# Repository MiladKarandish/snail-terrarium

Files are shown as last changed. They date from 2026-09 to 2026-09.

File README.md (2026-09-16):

# Automated Snail Terrarium

A smart, self-regulating snail habitat: a 46 × 28 × 37 cm moss-covered terrarium
with closed-loop humidity, temperature and light control, driven by an ESP8266
running [**Climate Panel Pro**](https://github.com/MiladKarandish/esp8266-climate-pro)
firmware. No cloud, no app — the controller serves its own real-time web
dashboard over WiFi.

> **Status:** the printed mist chamber is designed, verified (57/57) and being
> ordered. Hardware is specified; wiring, firmware configuration and tuning are
> in progress.

---

## 1. What this is

Land snails are simple to keep and unforgiving about exactly one thing: **the
climate**. Too dry and they seal themselves into their shells and stop eating;
too wet and stagnant and the tank grows mould and bacteria. Doing that by hand
means misting twice a day, every day, forever.

This project closes the loop:

- An **SHT31-D** sensor reads temperature and relative humidity inside the tank.
- When humidity drops below target, an **ultrasonic mist maker** fogs the tank.
- When humidity overshoots — or on a scheduled interval — a **fan** exchanges air.
- A **neon LED strip** runs a circadian day/night cycle so the live **moss**
  carpet gets a real photoperiod and the snails get a stable dawn/dusk rhythm.
- Everything is visible and adjustable from a phone browser on the local network.

### Design goals

| Goal | How |
|---|---|
| Hold 75–90 %RH without manual misting | SHT31-D → mist maker, hysteresis control |
| Keep air fresh, prevent mould | Fan on humidity ceiling + timed air exchange |
| Real day/night for moss and snails | PWM LED strip on a sunrise/sunset curve |
| Never cook or drown the animals | Sensor-fault failsafe forces outputs off |
| Fully local, no subscriptions | ESP8266 web dashboard, WebSocket, mDNS |
| Repairable and documented | Every pin mirrored in [HARDWARE.md](HARDWARE.md) |

---

## 2. The habitat

| Property | Value |
|---|---|
| Enclosure | Glass/acrylic terrarium, **46 × 28 × 37 cm** (L × W × H) |
| Volume | ≈ **47.7 L** (0.048 m³) |
| Floor area | ≈ **1288 cm²** |
| Substrate | Coco coir / peat + sphagnum, 5–8 cm deep (snails burrow to lay eggs) |
| Planting | Live moss carpet (sheet/cushion moss), optional ferns |
| Furnishing | Cork bark hides, calcium/cuttlebone dish, shallow water dish, food dish |
| Lid | Escape-proof, ventilated — snails climb everything and lift light lids |

### Climate targets

Defaults below assume a temperate species (e.g. *Cornu aspersum*, the common
garden snail). **Confirm against your species** before committing setpoints —
giant African land snails want it warmer (24–27 °C).

| Parameter | Target | Acceptable | Notes |
|---|---|---|---|
| Temperature | **20–22 °C** | 18–24 °C | Above ~26 °C is stressful; above 30 °C dangerous |
| Humidity | **80 %RH** | 75–90 %RH | Below 70 % → snails seal up; above 95 % → mould |
| Photoperiod | **12 h** | 10–14 h | Moss needs light; snails need shaded hides |
| Air exchange | Every 1–2 h | — | Short fan pulses; the tank must not go stagnant |

Full control strategy and setpoint mapping: **[AUTOMATION.md](AUTOMATION.md)**.

---

## 3. Hardware at a glance

| # | Component | Role |
|---|---|---|
| 1 | **ESP8266 (ESP-01)** | Controller — WiFi, web UI, automation logic |
| 2 | **SHT31-D** | I²C temperature + humidity sensor (±0.2 °C, ±2 %RH) |
| 3 | **PCF8574** | I²C 8-bit I/O expander — frees the ESP-01's TX/RX for outputs |
| 4 | **550 mL/h ultrasonic mist maker** | Humidifier — raises RH. **24 V DC, 0.75 A** — [MIST-MAKER.md](MIST-MAKER.md) |
| 5 | **Fan** | Air exchange / circulation — lowers RH, prevents mould |
| 6 | **1 m neon LED strip** | Circadian lighting, analog (non-addressable) |
| 7 | **2 × XY-MOS 400 W MOSFET module** | High-current switches for the loads |
| 8 | Power supply + buck converter | See [HARDWARE.md §Power](HARDWARE.md) |

> ⚠️ **Known gap:** there are **three** switched loads (mist maker, fan, LED
> strip) but only **two** MOSFET modules. A third switch is needed — see
> [HARDWARE.md](HARDWARE.md) for the recommended allocation and options.

Full bill of materials, pin map, wiring diagrams and power budget:
**[HARDWARE.md](HARDWARE.md)**.

---

## 4. System architecture

```
                    ┌──────────────────────────────────────────┐
                    │            TERRARIUM (47.7 L)            │
                    │                                          │
   ┌─────────┐ I²C  │  ┌──────────┐                            │
   │ ESP-01  │◄─────┼──┤ SHT31-D  │  temp + humidity           │
   │ ESP8266 │      │  └──────────┘                            │
   │         │      │                                          │
   │  WiFi   │      │  ┌──────────┐   ┌─────┐   ┌───────────┐  │
   │  web UI │      │  │  Mist    │   │ Fan │   │ LED strip │  │
   └────┬────┘      │  │  maker   │   └──▲──┘   └─────▲─────┘  │
        │ I²C       │  └────▲─────┘      │            │        │
        ▼           └───────┼────────────┼────────────┼────────┘
   ┌─────────┐              │            │            │
   │ PCF8574 │──────────────┴────────────┘            │
   │  0x20   │   on/off via XY-MOS MOSFET modules     │
   └─────────┘                                        │
        ESP-01 GPIO3 (PWM) ─────────────────────────────┘
                            dimmable circadian channel

   Phone / laptop ──WiFi──► http://snail-terrarium.local
```

**Control loop:** read SHT31-D once per second → compare against per-output
setpoints with a hysteresis dead-band → drive outputs through the PCF8574 (on/off)
and GPIO3 (PWM) → broadcast state to every connected browser over WebSocket.

---

## 5. Firmware

The controller runs **Climate Panel Pro (ESP8266 edition)** —
`~/Documents/arduino/esp8266-climate-pro`
([GitHub](https://github.com/MiladKarandish/esp8266-climate-pro)).

Relevant capabilities for this build:

- **Up to 8 independently-controlled outputs**, each named, each with a control
  mode: **Manual**, **Sensor** (temp/hum, above/below setpoint + hysteresis),
  **Schedule** (daily on/off times), or **Interval** (cyclic on/off).
- **Per-output invert (NC)**, an **active-time window** gating any mode, and an
  **anti-short-cycle** minimum switch time — important for the mist maker.
- **Sensor-fault failsafe**: a CRC-failed or missing SHT31-D forces every
  automated output off after 60 s rather than fogging forever.
- **Circadian LED channel** — sunrise → daylight → sunset → night brightness
  curve on an NTP-synced clock, or manual brightness.
- **Captive-portal WiFi setup** (no credentials in code), **mDNS**,
  **OTA updates** (web `/update` + ArduinoOTA), settings persisted in flash.
- **24 h history**, min/avg/max, trend arrows, per-output run-time counters.

Build flags this project requires (top of `esp8266-climate-pro.ino`):

```c
#define USE_PCF8574 1      // outputs on the expander; frees TX/RX, enables LED PWM
#define PCF_ADDR    0x20   // A0/A1/A2 → GND
```

With `USE_PCF8574 1` the firmware also enables `LED_SUPPORTED` on **GPIO3**, and
raises `MAX_OUTPUTS` from 2 to 8.

---

## 6. Repository layout

```
snail-terrarium/
├── README.md              ← you are here: what the project is
├── HARDWARE.md            ← bill of materials, wiring, pin map, power, safety
├── AUTOMATION.md          ← climate strategy, output config, tuning
├── MIST-MAKER.md          ← datasheet for the atomiser module
├── DESIGN-DECISIONS.md    ← why the printed parts are shaped the way they are
└── cad/                   ← the printed mist chamber
    ├── README.md          ← parts, print settings, assembly, commissioning
    ├── VIEWER.md          ← how to run the interactive 3D assembly
    ├── params.scad        ← every dimension, with its source
    ├── mister.scad        ← body, lid, trim spacer
    ├── checks.scad        ← geometry that exists only to be measured
    ├── verify.py          ← nothing is printed until this passes
    ├── assembly.scad      ← everything together, printed and bought parts
    ├── viewer.py          ← builds/serves/deploys an interactive 3D assembly
    ├── viewer/index.html  ← that assembly, self-contained. Open it anywhere
    ├── stl/               ← the printable meshes
    ├── render/            ← pictures of the assembly
    └── superseded/        ← earlier designs, kept for reference. Do not print.
```

Build the parts with `.venv/bin/python cad/verify.py` — it renders the STLs
into `cad/stl/`, lying the way they print, and fails loudly on a bad part. To see
how it all goes together, `.venv/bin/python cad/viewer.py` builds and serves an
interactive 3D assembly you can orbit, explode and section —
[cad/VIEWER.md](cad/VIEWER.md). It is live at <https://snail-terrarium-mister.vercel.app>.

Firmware lives in its own repository:
[`esp8266-climate-pro`](https://github.com/MiladKarandish/esp8266-climate-pro).

---

## 7. Roadmap

- [x] Define enclosure, species targets and component list
- [x] Document hardware, wiring and control strategy
- [x] Design and verify the printed mist chamber ([cad/README.md](cad/README.md))
- [ ] Print the chamber, leak-test it, assemble and commission the level
- [ ] Resolve the third-switch gap (mist maker / fan / LED)
- [ ] Confirm mist maker and fan operating voltages, size the PSU
- [ ] Bench-test: ESP-01 + SHT31-D + PCF8574 on one I²C bus
- [ ] Wire loads through the MOSFET modules, verify no brown-out on switching
- [ ] Flash with `USE_PCF8574 1`, configure the four outputs
- [ ] Seal, plant the moss, run empty for 1 week and log the climate
- [ ] Tune hysteresis and fan interval from the 24 h history
- [ ] Introduce the snails

---

## 8. Safety and animal-welfare notes

- **This module cannot run dry** — it carries its own conductivity probe and
  stops below 41 mm ([MIST-MAKER.md §3](MIST-MAKER.md)). That is worth stating
  plainly because most advice about ultrasonic foggers assumes the opposite, and
  every dry-run guard in the early versions of this design was solving a problem
  the hardware had already solved. What *does* kill it is **hard water**: scale
  on the disc halves the output within weeks and eventually cracks the ceramic.
  Use RO or distilled water.
- **Never PWM the mist maker.** Its driver is a self-oscillating inverter that
  needs continuous DC. Switch it on and off in whole seconds.
- **Keep all electronics outside the tank.** The inside is a permanently
  condensing 90 %RH environment; only the sensor and the LED strip go in, and
  the strip must be a sealed (IP65+) type.
- **Fog is not ventilation.** A snail tank that is wet *and* stagnant grows
  mould and pathogenic bacteria fast. The fan cycle is not optional.
- **Shade matters.** Snails are nocturnal and avoid light — always leave cork
  bark or dense moss they can hide under, no matter what the LED is doing.
- **Escape-proofing.** Snails are strong climbers and will find any gap large
  enough for their foot, cable pass-throughs included.
- **Low-voltage only.** Nothing in this build switches mains. If you later add
  a mains heater, that is a different and far more dangerous project — use a
  properly enclosed, rated relay module and follow local electrical code.

---

*Licensed MIT. Firmware pin definitions are the source of truth — if you move a
wire, update the matching `#define` and [HARDWARE.md](HARDWARE.md).*

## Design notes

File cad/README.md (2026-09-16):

# Bottle-fed mist chamber

The printed part of the terrarium: a chamber the ultrasonic module sits in, held
at a constant water level by an inverted bottle, with a fan blowing across the
fog and a nozzle carrying it to the tank.

Why it is shaped this way: **[../DESIGN-DECISIONS.md](../DESIGN-DECISIONS.md)**.
What the module needs: **[../MIST-MAKER.md](../MIST-MAKER.md)**.

```
                              ┌──────────┐
                              │  0.5 L   │   inverted, screws into a
                              │  bottle  │   captured PET cap
                              └────┬─────┘
      ┌────────────┐               │ Ø12 conduit, up the OUTSIDE
      │    lid     │◄─ cable out   │ of the wall
    ══╪════════════╪══             │
      │  ░░░ fog ░░│               │      fog out, 45° up, Ø25 hose
   ───┤            ├───────────────┤   ◄─ fan in, Ø26
      │▓▓▓▓▓▓▓▓▓▓▓▓│◄──────────────┘   ── water line, 46 mm ────────
      │▓▓ module ▓▓│  feed port, apex ON the water line: air can
      │▓▓▓▓▓▓▓▓▓▓▓▓│  only get in when the level drops past it
      └────────────┘
     ══════ foot ══════
```

## Parts

| File | Part | Qty | Size | PETG |
|---|---|---|---|---|
| `stl/mister_body.stl` | Chamber, feed column, bottle socket | 1 | 99 × 100 × 147 mm | 113 cm³, ~144 g |
| `stl/mister_lid.stl` | Lid with cable gland | 1 | 67 × 68 × 9 mm | 16 cm³, ~20 g |
| `stl/mister_spacer.stl` | Trim spacer — only if the level lands high, see *Commissioning* | 0–1 | 43 × 43 × 2 mm | 2 cm³, ~3 g |

Total for the build: **~132 cm³, ~167 g of PETG.**

Also needed, not printed:

- A **0.5 L still-water PET bottle** and its cap. Not carbonated — petaloid
  bases sit crooked. Any standard closure fits: 28 mm PCO-1881 or PCO-1810
  (soda) and 29/25 or 30/25 (water) are all within the socket's range.
- A **30, 40 or 50 mm fan**, 5 V or 12 V. The pad is drilled for all three
  (24, 32 and 40 mm bolt pitch) and is tall enough that **all four screws of any
  pattern land on flat pad**, not on the chamfer under it — see **D25**.
  4 × M3 screws. Pick on **static pressure, not airflow**: everything goes
  through the same Ø26 bore and Ø20 nozzle, so the duct sets the restriction and
  a small fast fan often beats a big slow one. 25 mm fans are not drilled (only
  1.3 mm of screw wall) and 60 mm will not fit the barrel.
- **25 mm ID hose** for the fog line, and a clamp or zip tie. The spigot
  gives it **15 mm** of clear seat, with room to clamp behind the end.
- **Epoxy** for the cap — and, if the service would not confirm ≥ 4 perimeters,
  a thin coat inside the chamber (see *Assembly*, step 0).
- **RO or distilled water.** Not optional — see [MIST-MAKER.md §5](../MIST-MAKER.md).

## Build

```bash
../.venv/bin/python verify.py
```

Renders the STLs into `stl/` and runs 57 checks. **It must print `57/57` before
anything goes to a printer.** It checks levels against the datasheet band, fits
and clearances, that the wall is unbreached below the water line, that the lid
seats *and* comes off, that the feed is actually open end to end, that a hose
will go far enough onto the nozzle, and that nothing on either part overhangs
past 45° in its print orientation. Five checks run twice, once with a defect
injected that must fail — a test that cannot fail is not a test.

It also writes `.build/facts.json`, which is where the viewer's title block gets
its figures, so nothing downstream quotes a number that was not verified.

Change a number in `params.scad`, run it again.

## Seeing it assembled

```bash
../.venv/bin/python viewer.py
```

Builds and serves an interactive 3D assembly at `http://127.0.0.1:8017/` — orbit
it, pull it apart with the explode slider, switch parts off, and drag the section
slider for a live cutting plane through the bore, the water and the feed port.
`--build` writes a single self-contained `viewer/index.html` you can open
straight off the disk, with no server and no network.

It is also live at **<https://snail-terrarium-mister.vercel.app>**; `viewer.py --deploy`
rebuilds and pushes it.

Full reference, controls and troubleshooting: **[VIEWER.md](VIEWER.md)**.

If you just want pictures rather than something to spin:

```bash
../.venv/bin/python viewer.py --stills
```

re-renders the five images in `render/` from the same model. `assembly.scad`
takes `EXPLODE` (0–1), `SECTION` and `BOTTLE` if you want a view of your own.

## How the level holds itself

Water only leaves the bottle if air can get in to replace it. That is not a
detail — it is the whole mechanism, and the port does both jobs:

```
   bottle                    air goes UP the same tube the water comes DOWN
     │  water down
     ▼  ▲ air up             1. level sits at the port's apex
   ┌────┴───┐                2. it drops slightly - evaporation, or a burst
   │        │  Ø12 conduit   3. the apex is now above water, exposed to the
   │        │                   chamber's air
   │   ┌────┴──┐             4. air bubbles in, rises the conduit, reaches
   │   │ apex  │ ◄─ port        the bottle
 ══╪═══╪══════════ water     5. an equal volume of water runs out, the level
   │   │       │                rises and re-seals the apex
```

Nothing measures anything and nothing switches. The level is set by where the
air can get in, which is a printed edge, and it is stable because sealing that
edge stops the flow.

Three things have to be true, and all three are checked or specified:

- **The conduit must be wide enough for air and water to pass each other.**
  Ø12; counter-flow stalls below about 6 mm. The whole air path — port, conduit,
  the hole you drill in the cap — is Ø10 or wider.
- **The chamber must be vented.** It is, through the fan bore and the nozzle,
  both well above the water. A sealed chamber cannot let air into the port and
  the feed stalls.
- **The bottle must be sealed except through the conduit.** That is the epoxied
  cap. If air leaks in past it, the bottle drains instead of regulating — which
  is the failure listed in *Commissioning*.

The fan blowing into the chamber does not shift the level: the same pressurised
air presses on the water surface *and* is what enters the port, so it cancels.

## Print settings

| | Body | Lid | Spacer |
|---|---|---|---|
| Orientation | Upright, open end up, on the foot | **Plate-top-down** — spigot up | Flat |
| Support | **None** | **None** | None |
| Material | PETG | PETG | PETG |
| Layer | 0.2 mm | 0.2 mm | 0.2 mm |
| Perimeters | **≥ 4** | ≥ 3 | ≥ 3 |
| Infill | ≥ 30 % | ≥ 30 % | ≥ 20 % |

The STLs are exported **already lying in these orientations** — a print service
slices a file as it is uploaded, so upload them as they are and do not rotate them.

**Perimeters are the setting that matters.** The wall is 1.6 mm, which is
*exactly* four extrusions at a 0.4 mm nozzle, so at ≥ 4 perimeters it is 100 %
shell with no infill inside it to weep through. At 2 perimeters the same wall is
0.8 mm of shell wrapped around 0.8 mm of infill, and it will seep no matter what
infill percentage is set. Ask for 0.2 mm layers rather than 0.1: half the layer
count, half as many interfaces, each one a potential leak path.

**Ordering from a service.** An online order form typically offers layer height,
material, colour, infill and scale — and neither perimeters nor orientation.
Orientation is handled: the STLs already lie the right way. Perimeters are not,
so **ask the service in writing for ≥ 4 walls on the body before paying**. Do not
buy watertightness with 100 % infill instead: it costs a third more for the body
and the epoxy fallback below does the job for nothing — see **D26**.

PETG, not PLA — PLA embrittles and creeps in constant water contact.

## Assembly

0. **Leak-test the body first.** Fill the chamber to ~50 mm and leave it
   overnight on a paper towel. A damp spot shows where the wall weeps; brush a
   thin coat of epoxy inside the chamber up to ~50 mm — floor, wall and around
   the feed port, but **not into the port** — and test again. Cheaper to find
   now than after the cap is glued in.
1. **No measuring needed.** The socket is cut for the finish standards, not
   for one cap: a ribbed Ø32.4 grip takes any closure from Ø29.5 to Ø31.4, and
   a Ø34.5 counterbore above it clears the bottle's Ø33 neck support ring
   whatever the cap height is. 28 mm PCO-1881, PCO-1810 and 29/25 or 30/25
   water caps all fit the same part — see **D24**.
2. **Drill the cap** through its flat top, ~Ø10, centred.
3. **Epoxy the cap into the socket**, drilled face down onto the pocket floor,
   threads up. Six ribs in the pocket stop it turning when the bottle is screwed
   in. The epoxy is doing two jobs: holding it and *sealing* it — any air leak
   around the cap and the bottle drains instead of regulating.
4. **Fit the fan** to the pad, blowing **inward**, with M3 screws in whichever
   bolt circle matches. The holes are blind; do not force a longer screw through.
5. **Push the hose** onto the 45° nozzle and clamp it. Run it **downhill** to the
   tank so condensate drains forward.
6. **Stand the module** on the chamber floor, inside the four locating lugs, with
   its cable out through one of the gaps between them.
7. **Thread the cable** up through the lid's hole from underneath. The
   countersink is on the lid's **underside**, so the module's own conical rubber
   bung seals from *below*: slide it down the cable towards the module first —
   at Ø14 it will not pass the Ø11.5 hole — then thread the plug up through the
   lid, and push the bung **up** into the countersink, narrow end first. The fan
   pressurises the chamber, which presses the bung tighter rather than out. The
   bung only slides, and the plug stops it coming off the cable, so check which
   way its narrow end points before you start.
8. **Fill the chamber** by hand to roughly 45 mm, screw on the filled bottle, and
   seat the lid.

To take it apart: unscrew the bottle, lift the lid a few mm until its spigot is
clear of the bore, then slide it sideways off the feed column.

## Commissioning

Run it with the lid off and watch the water line.

| What you see | What it means | What to do |
|---|---|---|
| Dense, low-lying fog | Correct | Nothing |
| Nothing, or it cuts in and out | Level is under the 41 mm probe | Check the bottle is sealed and the port is not blocked |
| Spitting, coarse droplets | Level is high, over ~50 mm | Fit the 2 mm trim spacer under the module |
| Bottle empties fast, chamber overflows | Air is leaking in past the cap | Re-seal the cap in the socket |

The level should settle between **43.5 and 46.0 mm** measured from the chamber
floor. It sits a little below the port's apex because air has to bubble in
before water can leave — about 2.5 mm on a Ø12 port. That is designed for; the
whole range is inside the module's 42–47 mm optimum.

The chamber holds **~58 mL** with the module in it — about **6 minutes** of
continuous fogging before the bottle has to keep up, which it does easily. At
20 mL/day a 0.5 L bottle lasts about **25 days**. Check it weekly at first: a
tank that leaks humidity will run the mister far harder than that, and the
bottle is the first place you will see it.

## Maintenance

- **Descale** in 50:50 white vinegar for 20–30 min when output drops. Lift the
  module out; never scrape the disc.
- **Never let it run on tap water.** Scale halves the output within weeks and
  eventually cracks the ceramic.
- The module is a **consumable** — potted, non-serviceable, 3000–5000 h. It
  lifts straight out when it dies.

## Files

| | |
|---|---|
| `params.scad` | Every dimension, with its source and its reason |
| `mister.scad` | The parts |
| `checks.scad` | Geometry that exists only to be measured. Not printed |
| `verify.py` | The gate — run this before printing anything |
| `section2d.scad` | True vertical section, rendered from the real solids |
| `assembly.scad` | The whole thing together, printed and bought parts. Not printable |
| `export_parts.scad` | Splits the assembly into meshes for the viewer |
| `viewer.py` + `viewer/` | Builds and serves the interactive 3D assembly — see [VIEWER.md](VIEWER.md) |
| `tools/pack_viewer.py` | Packs those meshes into the viewer's geometry blob |
| `stl/` | The printable meshes, binary STL. Written by `verify.py` |
| `render/` | Pictures of the assembly — assembled, detail, exploded, section, and a true vertical section as SVG. Written by `viewer.py --stills` |
| `superseded/` | Earlier designs. Kept for reference — **do not print** |

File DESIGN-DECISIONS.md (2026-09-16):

# Design Decisions

Why the printed parts are shaped the way they are. Each entry records what was
considered and what settled it, so a future change starts from the reasoning
rather than re-deriving it.

**Nothing here is deleted when it turns out to be wrong.** Several of these were
reversed — twice, in one case — and the reversals are the most useful entries in
the file. The index says which still hold, so you do not have to read all of it
to find out.

| | Decision | Status |
|---|---|---|
| **D1** | Mariotte reservoir, chosen on cost | dropped by D11, reinstated by D13 |
| **D2** | Nothing mounts on the terrarium lid | holds |
| **D3** | PETG, and the seal is not a print | holds, but the gasket became a captured bottle cap |
| **D4** | The fog port is a teardrop | superseded by **D18** — teardrops fix holes, not spigots |
| **D5** | The lid seats on the rim and prints upside down | holds |
| **D6** | Levels referenced to the module's top face | superseded by **D14** — datum settled from the datasheet |
| **D7** | Nothing is printed until `verify.py` passes | holds, and **D15**/**D16** say why it was not enough |
| **D8** | The chamber is a cut PET bottle | superseded by **D13** |
| **D9** | Wall thickness is a multiple of the nozzle | holds |
| **D10** | A jar would also work | superseded by **D13** |
| **D11** | The reservoir outlived its justification | **reversed by D13** |
| **D12** | Vents and the fog port are in series | holds, as the fan and the nozzle |
| **D13** | The module was measured, and it invalidated everything | **holds — the pivot** |
| **D14** | Open questions — mounting, and how the chamber fan is switched | live |
| **D15** | The design was audited by boolean, and it did not survive | holds |
| **D16** | A leak is a topology question, not a dimension | holds |
| **D17** | Nothing that must not leak is left to two cylinders grazing | holds |
| **D18** | A teardrop fixes a hole, not a protrusion | holds |
| **D19** | The cable leaves through the lid | holds |
| **D20** | The foot exists because the bottle is a lever | holds |
| **D21** | The level is not the port height | holds |
| **D22** | The assembly model is generated, not drawn | holds |
| **D23** | A tilted spigot is shorter than it looks | holds |
| **D24** | The socket is cut for the standard, not for one cap | holds |
| **D25** | A chamfer takes the seat away before it takes the overhang | holds |
| **D26** | The STL is the order, so it is exported the way it prints | holds |

If you read only three: **D13** (measuring the real module invalidated the whole
design), **D15** (the rebuilt design still had eight defects, three fatal) and
**D16** (why watertightness is checked by counting voids).

---

## D1 — Mariotte reservoir, chosen on cost.

**Settled by:** a 4 M toman quote for the reservoir-less design.

The wide 20–75 mm band made a plain chamber *possible* — hold ~445 mL across the
band and refill fortnightly. But possible is not cheap. Sizing a vessel by
`footprint x band` meant a 96 x 96 x 187.5 mm box: **293 cm3, ~373 g of PETG.**

An inverted-bottle (Mariotte / chicken-waterer) reservoir holds the level
**constant**, which changes what the chamber is for. Two consequences, both
saving material:

1. **Park the level at the bottom of the band, not the top.** Nothing has to
   drift, so the level sits at 25 mm above the module instead of filling to 73.
   The water column drops from 118 mm to **68.5 mm**.
2. **Capacity moves into the bottle.** The chamber no longer stores anything, so
   its footprint is set only by the 45 mm module — a **74 mm bore**, cylindrical,
   because a cylinder needs the least wall for a given volume.

```
                      volume    PETG     refill
  plain chamber       293 cm3   373 g    22 days
  bottle + siphon     134 cm3   170 g    25 days   (0.5 L bottle)
```

**~55 % less material for a longer refill interval.** The bottle is free,
transparent so the level is visible, and cannot leak the way a printed vessel can.

> How it regulates: the standpipe hangs from the lid, its bottom opening at the
> target level. Water leaves the bottle until it seals that opening; air can then
> no longer enter, so flow stops. As water is consumed the level drops, air
> bubbles up the standpipe, and more water flows out. **The chamber must stay
> vented** — the lid's air holes are not optional, or atmospheric pressure cannot
> act on the water surface and the siphon stalls.

> The standpipe is offset 16 mm from centre so it does not sit directly over the
> atomising disc. Free area past it is 5.5x the fog port's, so the plume is not
> choked.

## D2 — Nothing mounts on the lid.

A lid-mounted reservoir works out at 1.7–2.7 kg on ~130 × 130 mm. Mesh lids bow
under far less, 3 mm acrylic creeps permanently, and glass fails suddenly and
directly above the animals.

The decisive objection is not structural though: **the lid opens every day** for
feeding and checks. No design survives lifting 2 kg of sloshing water off a
hinge twice a day.

## D3 — PETG, and the seal is a gasket, not a print.

The print service is FDM-only. Service-printed parts are not reliably watertight,
because the service prints to its own profile rather than one tuned for water.

- **PETG** for everything touching water — no hydrolysis (PLA embrittles and
  creeps in constant water contact), tolerant of the 5–45 °C the module allows.
- **XFlex (TPU)** is on the service's material list, so gaskets are *printed*
  rather than sourced as O-rings.
- Print settings that matter: **100 µm layers, ≥4 perimeters, ≥40 % infill.**
- The chamber has **no wall penetration below the water line.** The module's
  cable exits over the rim through a notch. The only hole in the vessel is the
  fog port, 150 mm up — 30 mm above the fill line. Nothing below water can leak.

## D4 — The fog port is a teardrop.

A round horizontal hole has a 90° overhang at its crown and needs support. The
teardrop profile self-supports, so the chamber prints upright with **zero
support material** — cheaper from a service and no scarring inside a vessel that
has to stay clean.

## D5 — The lid seats on the rim, and prints upside down.

Two failed attempts are worth recording, because both looked fine on screen.

**A rebate is not a seat.** Cutting a lid rebate into a 3 mm wall leaves a ledge
only `lid_clear` wide — 0.35 mm. A flush drop-in lid resting on that would fall
into the chamber. The seat has to be the **rim** itself: a full 3 mm annulus.

**Do not seat on a printed overhang.** A plate-on-spigot lid printed spigot-down
leaves a 3 mm unsupported ledge around the perimeter — and that ledge is the face
that lands on the rim. It prints droopy and the lid rocks.

The fix is orientation: **print the lid plate-top-down.** The spigot and the fill
collar then both rise from the bed, there is not a single overhang on the part,
and the seating face is bed-flat. That is the only reason the fill collar points
*down* in use.

## D6 — Levels are referenced to the module's top face.

The module sits 1.5 mm down in its locating recess, so levels measured from the
chamber floor overshoot by that much — the fill line worked out at 76.5 mm above
the module against a 75 mm ceiling. `module_top` now carries the recess, and the
lines sit inside the band with margin: **fill at 73 mm** (2 mm below the ceiling)
and **refill at 25 mm** (5 mm above the floor, as a dry-run guard).

## D7 — Nothing gets printed until `verify.py` passes.

Renders hide defects; a 288 g PETG part is expensive to get wrong. `cad/verify.py`
asserts levels against the datasheet band, port placement, fits and clearances,
mesh manifoldness, and does a **boolean interference test** of the lid seated on
the chamber.

Two things make it trustworthy rather than decorative:

- **A positive control.** The same test runs with the lid dropped 1 mm, which
  *must* collide. Without it, an interference check that silently measures
  nothing passes forever.
- **No stale reads.** OpenSCAD writes no file when a result is empty, so the
  harness deleted the target before each render — otherwise the previous run's
  mesh is read back as if it were this one's. That bug made the check report a
  clean part as colliding and a colliding part as clean.

The control is what caught D5: a 17 mm³ collision, where the rim area predicted
~1100 mm³, is what revealed the seat was only 0.05 mm wide.

## D8 — The chamber is a cut PET bottle.

A real quote settled this: **2.44 M toman for the 83.6 g chamber**, ~29,000 per
gram. That is far above material cost, so the price is machine time, and time on
FDM tracks **layer count** — the chamber was 126.5 mm tall at 100 um, i.e. 1,265
layers.

Printing a plain water container at that rate is the worst possible use of the
budget. It holds water and locates the module; **a PET bottle cut into a cup does
both for nothing**, and is more watertight than any FDM part plus transparent, so
the level is visible.

```
                             printed   PETG    height
  original box               293 cm3   373 g   187.5 mm   (quoted 4 M)
  printed cylinder + lid      99 cm3   126 g   120 mm
  cut bottle + vessel_lid     40 cm3    51 g    66 mm
```

Two constraints that are easy to get wrong:

- **Not a saucer.** A bird waterer's dish is ~15 mm deep. This module is 45 mm
  tall and wants 20-75 mm *above* that, so the water is ~66 mm deep and the
  vessel is a bottle cut at ~120 mm.
- **Not a carbonated bottle.** Soda bottle bases are petaloid - five domed feet -
  so the atomiser would sit tilted. Use a still water, juice or milk bottle,
  which have near-flat bases.

The lid's skirt is a shallow **cone**, self-centring over a 5 mm spread of
diameters, because bottle diameters vary by brand and the user should not have
to match a number exactly. It needs no seal: water sits at 66.5 mm and the joint
is at 120 mm, so it is never wet. Only the bottle-neck socket seals, via a
printed TPU washer.

## D9 — Wall thickness is a multiple of the nozzle, not a strength number.

Hydrostatic load here is trivial - 0.02 MPa hoop stress against PETG's ~50 MPa.
Wall thickness is set by **watertightness**, and watertightness is set by
perimeters, which a print service's calculator does not expose.

At 2 perimeters on a 0.4 mm nozzle, a 2.0 mm wall is 0.8 mm of shell wrapped
around 1.2 mm of 20 % infill - a porous sandwich that weeps no matter what infill
is set to. **1.6 mm is exactly 4 extrusions**, so the wall is 100 % shell.
Thinner is both cheaper and more reliable. Keep it a multiple of 0.4.

For the same reason, ask for **200 um layers, not 100**: half the layer count, and
half as many layer interfaces, every one of which is a potential leak path.

## D10 — A jar would also work.

The chamber is still two thirds of the print. It does nothing clever: it holds
water and locates the module. **Any watertight container with a >=70 mm bore and
>=130 mm depth would do the same job for near-nothing**, leaving only the
lid/standpipe assembly to print:

```
  chamber + lid + gasket    134 cm3   170 g
  lid + gasket only          47 cm3    59 g     ~65 % less again
```

Not adopted yet only because it needs a specific container to design the lid
around. If a suitable jar is available, that is the cheapest version of this
build by a wide margin.

## D11 — The reservoir outlived its justification.

Re-derived from scratch after the vessel became free. **The Mariotte reservoir
was correct only while the vessel was printed.**

Its purpose was holding the level constant so an *expensive* vessel could be
small: capacity cost `footprint x band` in PETG. Once the vessel became a cut
bottle, capacity became free — and the reason for the reservoir vanished. It was
carried forward on momentum, not on a reason that still held.

With a 55 mm band and a Ø88 bottle, the level can simply drift down the band:

```
  π/4 × 88² × 55 mm = 334 mL ÷ 20 mL/day  ≈ 17 days   (1.5 L bottle)
  π/4 × 103² × 55   = 458 mL              ≈ 23 days   (2 L bottle)
```

The reservoir bought endurance obtainable for free by cutting a bigger empty
bottle. What it cost: a standpipe, a TPU neck seal, a second bottle to mount and
keep upright, a siphon that can stall if the vents block — and **50 mm of part
height**, which is the cost driver.

```
                          printed   PETG   height   layers @100 um
  bottle + Mariotte lid   37.7 cm3   48 g   66 mm      660
  bottle + simple lid     26.1 cm3   33 g   15 mm      150
```

`vessel_lid` is kept for anyone who wants a genuinely constant level — steadier
fog output across the cycle — but it is not the default.

**The lesson worth keeping:** when a constraint disappears, re-derive the
decisions that were made to satisfy it. Three of them here were downstream of
"the vessel is expensive", and all three fell together.

## D12 — Vents and the fog port are in series.

Air in and fog out are the same flow path. The **smaller** opening sets
throughput, so vent area must be at least the port area. The original 5 x Ø5 mm
vents were 98 mm² against a 491 mm² port — **throttling the outlet to 20 %**.
Vents are now sized to ~1.15x the port, and `verify.py` checks the ratio on both
lids. Enlarging them also removes material.

## D13 — The module was measured, and it invalidated everything.

Handling the real part and running it in a bowl produced two numbers that no
amount of reading had given:

```
  module height        45 mm     (spec was right; my photo estimate of 29 was not)
  starts working       41 mm     water depth from the VESSEL FLOOR
  works                42-50 mm
  labours / splashes   >50 mm
```

The vendor's "effective water level 20-75 mm" is measured **from the ceramic disc
down in the well**, not from the base — which is why it never matched anything.

Three consequences, in order of importance:

**1. The usable band is 9 mm, not 55.** An unregulated vessel drifts from 41 to
50 mm and stops. On a Ø88 bottle that is ~3 days. **This reverses D11.** Dropping
the reservoir was correct arithmetic on a 55 mm band and simply wrong on a 9 mm
one. Level regulation is what makes this practical, not a refinement.

**2. The feed has to run outside the chamber.** The module is Ø45 *and* 45 mm
tall, and water sits at 44 mm. A standpipe hanging inside beside it needs a **Ø80
bore** to clear — and wall area goes with the square, so that is the difference
between a cheap part and an expensive one. Running the feed up the outside and
into a port at the water line keeps the bore at Ø60.

**3. It cannot run dry.** The unit has its own level probe and stops at 41 mm.
Every dry-run guard in the earlier designs was solving a problem the hardware had
already solved.

Everything drawn before this is in `cad/superseded/`.

## D14 — Open questions

- ~~**Water level datum.**~~ **Settled** by [MIST-MAKER.md](MIST-MAKER.md): the
  disc sits ~22 mm above the base in a recessed well, and the vendor's
  "20–75 mm" is the column *above the disc*. Depths here are total depth from
  the surface the module stands on, which is the chamber floor.
- **Mounting.** Hang-on-back bracket vs. table stand — deferred deliberately.
  The chamber is mounting-agnostic; the bracket is a separate part, so this
  choice does not block anything.
- ~~**Cap dimensions.**~~ **Settled by [D24](#d24--a-socket-cut-for-the-standard-fits-every-cap-a-measured-one-fits-one)**:
  the socket is cut for the finish standards instead of for one measured cap,
  so nothing has to be measured before printing.
- **How the chamber fan is powered and switched.** The pad takes a 30, 40 or
  50 mm fan (**D25**), but [HARDWARE.md](HARDWARE.md) and
  [AUTOMATION.md](AUTOMATION.md) only know a separate 40–80 mm tank fan on its
  own output. Fog is denser than air and the lid is closed, so the chamber fan
  is what carries it down the hose — it should run whenever the mister does.
  Three ways, undecided: wired **in parallel with the mister's switch** (no
  extra output; the fan needs its own voltage from the buck); **one fan doing
  both jobs** (running it without mist is air exchange through the chamber, but
  it caps the fan at 50 mm); or **its own output** on the spare P4 (can run on
  after the mister stops to clear the hose, at the cost of the spare). Nothing
  printed depends on the answer.

## D15 — The design was audited by boolean, and it did not survive.

Everything from D13 onwards was drawn, rendered, checked by a harness that
reported 26/26, and looked right. Measuring it with booleans instead of reading
it found **eight defects, three of them fatal**:

```
  feed bore blocked by a 3 mm slug          337.9 mm3 of PETG across the conduit
  lid collided with the bottle socket       375.6 mm3 - it could not be fitted
  2 of 4 fan screw holes opened into the      1.7 mm3 breach at z 46.4-49.4,
    chamber BELOW the water line                     under water
  fan bore dipped 0.4 mm under the water    breach at z 49.0-49.4
  nozzle spigot bonded to the barrel by       0.2 mm3 - a hairline
  module "recess" cut into the UNDERSIDE    0.9 mm membrane holding the water
  fan bore was a plain horizontal hole      needed support the file said it did not
  flange was a 2.5 mm square ledge          a 90° overhang right round the part
```

The first two mean the thing could not be assembled, let alone work. Every one
was invisible in a render and invisible to arithmetic.

**What made the old harness miss them:** it checked *numbers* — is the port at
the water line, does the module fit the bore — and every number was right. The
defects were all in the *relationships between solids*, which only a boolean
sees. `verify.py` now renders the real parts and asks topological questions of
them; `checks.scad` exists only to be measured.

## D16 — A leak is a topology question, not a dimension.

The strongest check in the harness does not measure anything. It takes a box up
to the water line, subtracts the body, and **counts the voids**:

```
  2  correct: the wetted cavity (joined to the conduit through the port,
              which is the entire point of the port) and the outside air
  1  the wall is breached somewhere - it leaks
  3  the port never connected - the bottle feeds nothing
```

One number, and it cannot be satisfied by accident. It caught a defect that
arithmetic could not: the nozzle was tilted with `rotate([-45,0,0])`, which
tips +Y **downward**, so the fog outlet left the wall *below* the water line.
The parametric clearance check passed — it was computing where the nozzle was
*supposed* to be. The void count went to 1.

Every boolean check that can have a control has one: the lid one millimetre low
*must* collide, a 3 mm hole through the wall *must* merge the voids, a slug in
the conduit *must* split it. A test that cannot fail passes forever.

## D17 — Nothing that must not leak is left to two cylinders grazing each other.

The old feed column relied on the conduit and the barrel overlapping by 1.2 mm
where their surfaces crossed. That is a cusp: a zero-angle crevice, the weakest
joint FDM can produce, and the feed port was bored straight through it.

The conduit is now joined to the barrel by a **solid web**, and the web is
deliberately wider than the port (18 mm against 12). That matters for more than
strength: if the port broke out of the web's side, air would reach the conduit
directly and the Mariotte would stop regulating and simply drain.

The same rule killed the old fan pad and nozzle. A flat plate floating off a
Ø63 barrel touches it along a sliver — the nozzle's entire bond to the chamber
was **0.2 mm³**. The fan pad is now a boss filled solid back to the barrel, and
the nozzle starts *inside* the bore so the wall cut trims it, rather than being
butted against the outside.

## D18 — A teardrop fixes a hole. It cannot fix a protrusion.

Teardrops were used everywhere on the old part, including places they do nothing.
The distinction:

- A horizontal **hole** can be given a 45° roof, because the material above it
  is ours to shape. Every hole here is a teardrop — fan bore, feed port, even
  the Ø3.2 screw holes.
- A horizontal **protrusion** cannot. The underside of a round spigot sticking
  out of a wall is a 90° overhang whatever its cross-section, and cutting it
  back to 45° leaves a V that no hose will seal against.

So the nozzle is **tilted 45° up**. An inclined cylinder has every normal on its
underside at exactly the tilt angle, so at 45° the spigot *and its bore* are
self-supporting while staying perfectly round for the hose. Fog rises into it,
and condensate runs back into the chamber instead of dripping out of the hose.

The remaining overhang on the whole body is **9.4 mm²** of tessellation facets
at 48°, around the teardrop screw holes (13.9 mm² once **D25** drilled twelve of
them). `verify.py` measures this on the actual triangles, in the actual print
orientation. The lid used to be flipped in memory for that; since **D26** the
STL itself is exported plate-top-down and nothing is flipped.

## D19 — The cable leaves through the lid.

The old design notched the rim. A notch is free to print but it is a hole in the
side of a fog generator: fog leaves through it and runs down the outside.

MIST-MAKER.md §4 records something the earlier work did not know — the cable
ships with **a sliding conical rubber bung, 14 mm tapering to 11 mm, meant for a
chamfered hole**. A hole in the lid is vertical in the print, so it comes out
round and takes that bung. The countersink is on the lid's underside, so in the
plate-top-down print it *widens* as it rises and needs no support either — and
in use the bung seats from inside the chamber, where the fan's pressure pushes
it in rather than out. The rim notch, and the matching notch in the lid that had
to line up with it, are both gone.

## D20 — The foot exists because the bottle is a lever.

A full 0.5 L bottle is **520 g on a 41 mm arm, 190 mm up**. Standing on the
barrel alone, the centre of mass sits about 30 mm off-axis inside a support edge
at 48 mm: the assembly tips at roughly 5°, next to a glass tank full of animals.

The foot is a 2.4 mm plate hulled from the barrel out under the column. It also
anchors a 145 mm tall print to the bed, which a Ø63 footprint does not.

**A bottle larger than 0.5 L must be supported independently.** 1.5 L is 1.5 kg
on the same arm and no foot fixes that.

## D21 — The level is not the port height.

Air has to break *into* the port as a bubble before water can leave, and that
costs `4σ/d` of head — **2.5 mm of water on a Ø12 port**. The level therefore
settles somewhere between the port's apex and 2.5 mm below it.

That is why the port is Ø12 rather than something tidier: the head goes as `1/d`,
so a narrow port is a level *error*, not a saving. And it is why the target is
**46 mm rather than the arithmetic centre of the 42–47 band**. Centring the port
would have put the low end of the real range at 42.0 mm — 1.0 mm from the probe
cut-off that stops the unit. At 46 the real range is 43.5–46.0, entirely inside
the band, clearing the probe by 2.5 mm and splashing by 4.0.

The 2 mm trim spacer covers the other direction: fit it under the module if the
level lands high and the unit spits droplets instead of fog.

## D22 — The assembly model is generated, not drawn.

Once the parts were rebuilt, the obvious next thing was a picture of them
together. The temptation is to model that separately — quicker to draw, and it
only has to *look* right.

`cad/assembly.scad` instead `include`s `params.scad` and `use`s `mister.scad`,
so the printed parts in it are literally the printed parts. The bought parts are
built from their own documentation rather than from memory: the module from
[MIST-MAKER.md](MIST-MAKER.md) §4 (Ø45 potted base, 20 mm splash collar, Ø20
disc recessed at 22 mm, probe beside it), the reservoir as a standard PET neck
finish. So the fits it shows are the real fits, and a change to `water_hold`
moves the water in the picture.

The same file feeds the interactive viewer through `export_parts.scad`, which
means the browser model, the rendered stills and the STLs the printer gets all
come from one set of numbers. A separately-drawn assembly would have been a
fourth version of the truth, and the whole point of D15 is that this design has
already been bitten by versions of the truth that only looked right.

Two things fell out of building it that are worth keeping:

- **It made D20 obvious.** The chamber is 99 mm; with the reservoir the assembly
  is 322 mm, and nearly all the mass is at the top on a 41 mm arm. The
  arithmetic said the same thing, but nobody feels an arithmetic tipping moment.
- **WebGL sections beat OpenSCAD sections.** OpenSCAD paints cut faces in the
  colour scheme's cutout colour whatever `color()` says, and `--render` discards
  per-part colours entirely; capping the cut with a real `projection()`
  cross-section works but costs a CGAL render per part. A clipping plane in the
  browser does it per fragment, in colour, live, and is draggable.

How to run it: **[cad/VIEWER.md](cad/VIEWER.md)**.

## D23 — A tilted spigot is shorter than it looks.

Spotted in the viewer, not in a check: the fog nozzle looked far too short to
push a hose onto. Measuring it was worse than looking at it. Sliding a modelled
hose down the nozzle axis until it fouled the barrel gave **under 4 mm** of
usable seat on an 18 mm spigot.

The reason is geometry that only applies to an *inclined* protrusion. A spigot
leaving a round barrel at 45° is buried unevenly — its upper side runs much
deeper into the wall than its lower side — and the hose stops against the
**short** side. Worse, it is the hose's outer *back corner* that hits first, not
its bore, so the length lost is set by the hose's OUTER radius:

```
  lost to clearing the barrel = (hose OD/2) x tan(tilt)
                              = (25/2 + 3) x tan(45°)
                              = 15.5 mm
```

Fifteen and a half millimetres of an 18 mm spigot were spent before the hose
could touch any of it. The screen showed a nozzle of respectable length, and
essentially none of it was usable.

**The fix is to derive the length rather than pick it.** `nozzle_len` is now
`hose_engage + (nozzle_od/2 + hose_wall)*tan(nozzle_tilt)` — 30.5 mm, of which
15 mm is clear seat with room to clamp behind the hose end. `verify.py` slides
the real hose down the real axis and checks it fouls nothing, with a control at
+8 mm that must foul.

**What it costs.** The nozzle rises at 45°, so a longer one reaches higher, and
the chamber is derived to keep it clear of the flange. The chamber grew from
98.9 mm to **107.7 mm**, and the build from 129 g to **137 g** — about 8 g, or
6 %, for a hose joint that actually holds. Both numbers fall straight out of
`params.scad`; shortening `hose_engage` shortens the part again if that trade
ever looks wrong.

**Why no check caught it.** Every existing nozzle check asked about the *bore* —
does it clear the water, does it clear the flange, does it throttle the fan. Not
one asked whether the thing a human has to attach could be attached. That is a
recurring shape in this design's history (D15, D16): the checks tested the part
against itself, and the defect was in the part's relationship to something else.
The new check models the hose.

## D24 — A socket cut for the standard fits every cap. A measured one fits one.

`cap_od` and `cap_h` were the last two numbers in `params.scad` marked MEASURE,
and they cut real geometry: the pocket, the anti-rotation ribs, and — through
`pocket_depth = cap_h + 1` — the height of the socket's top face. Getting them
wrong meant reprinting a 115 g part. Looking up what caps actually are showed
the guard was aimed at the wrong number:

```
  28 mm PCO-1881  soda, 2009-    cap Ø30.4 ±0.3   11-13 mm tall
  28 mm PCO-1810  soda, older    cap Ø31.0 ±0.4   14-17 mm tall
  29/25, 30/25    still water    cap Ø29.5-31      8-12 mm tall
```

**Diameter varies by under 2 mm. Height varies by 9 mm** — and height was the
one wired into the geometry. ISBT drawing 3784253-21 says why that matters: the
bottle's **neck support ring is Ø33.00**, sitting **H = 15.24 mm** below the
sealing face. The ring is *wider than the cap*, so it can never enter a Ø31.7
pocket; it has to stop on the socket's top face, and that face was pinned to
cap height:

```
  cap  9   mm tall  ->  +7.24 mm   OK
  cap 14   mm tall  ->  +2.24 mm   OK      <- what was drawn
  cap 16.5 mm tall  ->  -0.26 mm   the bottle cannot seat
```

The fix is not to measure better. It is to stop the part caring: a **ribbed
Ø32.4 grip** for the bottom 8 mm, and a **Ø34.5 counterbore** above it that the
support ring drops into whatever the cap height turns out to be. One body fits
every finish above, and a hole that widens as it rises adds no overhang, so it
costs nothing to print. The socket goes Ø38.1 → Ø40.9 and the part grows 2.3 mm.

The grip height is not a measured clearance but an argument from the finish: a
cap has to clear the support ring to screw on at all, so **the ring is always at
or above the cap's rim**. A ribbed section no taller than the shortest cap is
therefore below every ring there can be.

**And the harness could not see any of this.** `checks.scad` modelled the bottle
as a bare `cylinder(d = bottle_body_d, h = 250)` starting *above* `socket_top` —
no neck, no support ring — while `assembly.scad` drew the ring correctly for the
viewer. The two models disagreed, and the gate was using the blind one. It now
models the real finish. Exactly the lesson of **D15**, found again in the joint
**D14** called the one the Mariotte depends on.

The first control written for it was itself worthless, which is worth recording.
It filled the counterbore back in and expected the ring to collide — and it
reported **0 mm³**, because a PCO-1881 ring lands at 16.74 mm, *above* the 16 mm
socket top, in free air. The counterbore is for **short** necks, and the test was
seating a long one. A control that injects a defect the modelled case never
meets proves nothing at all.

So the envelope is tested instead of a guess: rather than invent a neck height
for a water finish there is no drawing for, the same neck is seated at the
**lowest ring that can physically occur**. A cap has to clear its own support
ring to screw on, so the ring is never below `cap_h_min`. That is the worst
point the design promises to handle, and filling the counterbore under it does
collide — by 217 mm³.

That test then failed twice more, both times in the harness rather than the
part, which is worth recording because both were mine.

**8.24 mm³ at the socket rim, and it was fictitious.** Rewriting `bottle()` had
quietly dropped the Ø25 × 4.5 straight section that `assembly.scad` has always
had between the support ring and the shoulder. Without it the shoulder starts
*at* the ring, so it was Ø35.25 by the time it reached the socket top instead of
Ø26.86, and fouled a Ø34.5 bore by 0.4 mm. No bottle is shaped like that — a
filling line's neck grippers need that straight section. The fix was to the
model, not the socket. `neck_straight` is flagged in `params.scad` as the one
dimension in the neck the ISBT drawing does not cover.

**And 8.24 mm³ before that, which was not fictitious.** The grip had been set to
`cap_h_min` exactly, so its top face and the lowest possible ring's underside
landed on the same z and the Ø33.2 ring came to rest on the Ø32.4 bore's edge —
0.20 mm of overlap across a 41.2 mm² annulus. The structural argument gave a
correct *bound* and was then used as if it were a *clearance*. The grip now
stops 1 mm below it (`cap_grip_margin`), and 7 mm still grips the shortest cap
over most of its height.

## D25 — A chamfer takes the seat away before it takes the overhang.

The fan pad carries two bolt patterns, 24 mm and 32 mm, so whichever fan is in
stock will fit. **D15** put a 45° chamfer under the pad, correctly: its flat
underside would otherwise have been the one horizontal ceiling on the part. What
nobody followed through was what the chamfer does to the *face above it*.

The seating face only exists where the chamfer cone has grown past the corner it
has to reach. That distance is not constant — it goes with `y`:

```
  ch_od/2 = 31.6                 the barrel
  face at sqrt(34.6² + y²)       how far out the flat face really is

  y =  0    face at 34.60    chamfer eats 3.00 mm of the pad
  y = 12    face at 36.62    eats 5.02 mm   <- 30 mm fan bolt circle
  y = 16    face at 38.12    eats 6.52 mm   <- 40 mm fan bolt circle
```

On a 42 mm pad that put the 40 mm fan's **lower two screws 1.75 mm below where
the flat face starts** — their holes opened onto the chamfer. A 30 mm fan was
fine, with 4.29 mm to spare. So "drilled for both" was half true, and the half
that failed was the more common fan.

The consequence is not cosmetic: the fan frame would bridge a gap at its lower
edge and those two screws would be tightened into a slope, loading them in
bending and levering at the chamfer's edge.

The pad height is now **derived from the widest pattern it claims to take**
rather than picked:

```
  fan_pad = fan_pitch_max + 2*fan_seat + 2*(fan_face_r - ch_od/2)
```

which leaves exactly `fan_seat` of flat under the lowest screw by construction,
whatever patterns the pad carries. `fan_pad_top` stays below `nozzle_top`, so
`ch_h` does not move.

**And since the pad now sizes itself, it may as well carry a third pattern.**
Which fan actually does the job through a Ø26 bore is a question you answer by
trying them, so 24, 32 and 40 mm pitches are all drilled: 30, 40 and 50 mm fans
bolt straight on, and `fan_pad` follows the widest at 59.93 mm. Twelve blind
holes, 2.46 mm of material between the closest pair.

The range is bounded at both ends by the barrel, not by choice:

```
  25 mm fan  20 mm pitch   1.3 mm of screw wall   under the 1.6 limit
  30 mm fan  24 mm pitch   2.1 mm                 the tightest one drilled
  50 mm fan  40 mm pitch   7.2 mm                 pad_top 98.2 < 99.7
  60 mm fan  50 mm pitch   pad wraps past the barrel AND pushes ch_h up
```

The narrow end is the dangerous one and it is not obvious: the barrel curves
*closest to the pad* at small pitches, so it is the 30 mm fan's screws, not the
50 mm fan's, that come nearest to opening into the water. `verify.py` takes
`fan_pitch_min` for that check and `fan_pitch_max` for the seat, which are
different patterns.

Worth saying plainly, since it decides what to buy: **fan diameter is not what
sets performance here.** Every fan blows through the same Ø26 bore and out the
same Ø20 nozzle, so the duct is the restriction and what matters is static
pressure, not the airflow figure on the box. A 30 mm at 12 V can beat a 50 mm
at 5 V.

**The check is geometric, and its control is history.** `verify.py` now finds
the pad's seating face on the real triangles — normals at −x, at the pad plane —
and measures how far the flat reaches down at each bolt circle. Run it against
the body committed before this change and it reports −1.75 mm and fails. A test
whose control is the part you shipped yesterday is the cheapest one to trust.

The pattern is the same as **D24**: a feature added for a good reason (there, a
counterbore; here, a chamfer) quietly consumed something else the design needed,
and no check was watching the thing it consumed.

## D26 — The STL is the order, so it is exported the way it prints.

**Settled by:** placing the first real order, with
[digisaaz](https://digisaaz.com).

`verify.py` had always checked the lid's overhangs *flipped*, because it prints
plate-top-down. But the STL it wrote was the lid as modelled — spigot down, plate
on top — and the gate passed. The file was right for the harness and wrong for
the printer. Uploaded as it was, the whole plate would have printed over air:

```
  lid as exported    3062 mm2 overhanging past 45°
  lid plate on bed      1 mm2  (the countersink nicking the spigot's top)
```

A print service slices **the file as uploaded**. This one's order form offers
exactly five choices and none of them is orientation:

```
  technology    FDM only
  layer         300 / 200 / 100 µm
  material      PETG among seven; black, white or clear
  infill        a free percentage
  scale         a percentage
```

So `mister.scad` now turns the lid over at export, and every STL in `stl/` lies
the way it prints. It is a rotation about x, not a z-mirror — a mirror would
move the cable hole to the other side of the feed relief and still pass every
check. The assembly, section and viewer load `mister.scad` with `use<>`, which
skips the part selector, so they still see the lid as modelled. `verify.py` no
longer flips anything: the overhang check now reads the file exactly as it is
uploaded.

**Perimeters are not on the form either**, and they are what **D9** makes the
wall watertight with. Infill is, and it was tempting to use it as the fix —
at 100 % a 2-perimeter wall is solid anyway. The quote said what that costs:

```
  body at 100 %    145.4 g    2,098,315 toman
  body at  30 %     99.1 g    1,579,802 toman    -25 %
```

Most of the body is 1.6 mm wall that is solid at any infill, so the saving is
real but not dramatic — and 100 % buys watertightness the hard way. The order
is set at 30 % instead, and the wall count is asked of the service in writing
before paying. If a service will not commit to ≥ 4 perimeters, the fallback
is not more infill: brush a thin coat of epoxy inside the chamber up to ~50 mm,
and leak-test the body overnight on a paper towel before assembling anything.

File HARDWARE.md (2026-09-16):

# Hardware & Wiring — Automated Snail Terrarium

Everything needed to build the electronics for the
[Automated Snail Terrarium](README.md). Every pin here mirrors a `#define` in
[`esp8266-climate-pro.ino`](https://github.com/MiladKarandish/esp8266-climate-pro) —
the firmware is the source of truth; this document tracks it.

> This is an **entirely low-voltage build** (3.3 V logic, 5–24 V loads). Nothing
> here switches mains. Keep it that way unless you are qualified to do otherwise.

---

## 1. Bill of materials

### Core electronics

| Qty | Part | Spec / notes |
|:--:|---|---|
| 1 | **ESP-01 / ESP-01S (ESP8266)** | ESP-01**S** = 1 MB flash — **required** for OTA updates |
| 1 | **SHT31-D breakout** | I²C temp + humidity, addr **0x44** (or 0x45); firmware auto-detects |
| 1 | **PCF8574 module** | I²C 8-bit I/O expander, addr **0x20** (A0/A1/A2 → GND) |
| 2 | **XY-MOS 400 W MOSFET module** | High-power N-MOSFET switch, PWM-capable trigger input |
| 1 | **Third switch — see §5** | A 3rd XY-MOS, or a small logic-level N-MOSFET board |
| 1 | **USB-serial adapter** | CH340 / CP2102 / FTDI at **3.3 V logic** — first flash only |

### Loads

| Qty | Part | Typical spec — **confirm yours** |
|:--:|---|---|
| 1 | **Ultrasonic mist maker, 550 mL/h** | **24 V DC, 0.75 A (18 W)** — confirmed [ECA 3791](MIST-MAKER.md) |
| 1 | **Fan** | 5 V or 12 V DC, 0.1–0.3 A (40–80 mm) |
| 1 | **Mist chamber fan** | **30, 40 or 50 mm**, 5 V or 12 V DC — blows the fog down the hose. Pick on static pressure ([cad/README.md](cad/README.md)). How it is switched is **not decided yet** — see D14 in [DESIGN-DECISIONS.md](DESIGN-DECISIONS.md) |
| 1 | **Neon LED strip, 1 m** | Analog (**not** WS2812/addressable), 12 V, ~0.5–1 A/m, **IP65+** |

### Passives & power

| Qty | Part | Purpose |
|:--:|---|---|
| 2 | 4.7 kΩ resistor | I²C pull-ups on SDA and SCL → 3.3 V |
| 1 | 10 kΩ resistor | ESP-01 CH_PD (EN) pull-up → 3.3 V |
| 1 | 10 kΩ resistor | (optional) ESP-01 RST pull-up → 3.3 V |
| 3 | 4.7 kΩ resistor | Pull-ups on the PCF8574 output pins — **see §6, this is not optional** |
| 1 | 0.1 µF ceramic | PCF8574 decoupling, **at the chip** — see §6 |
| 1 | 100 µF electrolytic | Bulk cap on the PCF8574 / 3.3 V rail |
| 1 | Main PSU | See §4 — sized from your mist maker's voltage |
| 1–2 | Buck converter (e.g. MP1584 / LM2596) | Step down to 12 V and/or 3.3 V |
| 1 | 3.3 V regulator ≥ 500 mA | ESP-01 is power-sensitive; do **not** feed it 5 V |

---

## 2. Signal glossary

| Signal | Meaning | Level |
|---|---|---|
| **SDA** | I²C data — shared by SHT31-D **and** PCF8574 | 3.3 V |
| **SCL** | I²C clock — shared by both | 3.3 V |
| **P0…P7** | PCF8574 expander outputs — drive the MOSFET module triggers | 3.3 V (see §6) |
| **GPIO3 (RX)** | ESP-01 PWM output → LED MOSFET gate | 3.3 V |
| **CH_PD / EN** | ESP-01 chip enable — must be HIGH to run | 3.3 V |
| **GPIO0** | I²C SDA in normal use; **tie LOW at boot to flash** | 3.3 V |
| **GND** | Ground — **every module shares one common ground** | 0 V |

**The golden rule:** ESP, sensor, expander, MOSFET modules and every power
supply share one common GND. Without it nothing works reliably.

---

## 3. Pin map (TL;DR)

```
ESP-01                     PCF8574 @ 0x20
  GPIO0  = SDA  ──────┬──► SHT31-D SDA
  GPIO2  = SCL  ──────┼──► SHT31-D SCL          P2 → MOSFET #1 trigger  (Mist maker)
  GPIO3  = LED PWM    └──► PCF8574 SDA/SCL      P3 → MOSFET #2 trigger  (Fan)
  GPIO1  = TX (free, serial log)                P4 → MOSFET #3 trigger  (spare / heater)
  CH_PD  = 3.3 V via 10 kΩ                      P0,P1,P5,P6,P7 → free
  VCC    = 3.3 V (≥500 mA)
```

Firmware `#define`s these live behind:

| Wire | `#define` | Value |
|---|---|---|
| SDA | `SDA_PIN` | `0` |
| SCL | `SCL_PIN` | `2` |
| LED PWM | `LED_PIN` | `3` |
| Expander enable | `USE_PCF8574` | `1` |
| Expander address | `PCF_ADDR` | `0x20` |
| Output → pin | `PCF_BIT[]` | `{2, 3, 4, …}` |
| Load polarity | `RELAY_ACTIVE_LOW` | `1` direct-drive · **`0`** if you invert per §6 |

> `USE_PCF8574 1` is what makes this build possible: it moves the outputs off
> TX/RX, which frees **GPIO3 for LED PWM** and raises `MAX_OUTPUTS` from 2 to 8.

---

## 4. Power

### Budget

| Rail | Consumer | Draw |
|---|---|---|
| 3.3 V | ESP-01 (WiFi TX peaks) | ~80 mA avg, **300 mA peak** |
| 3.3 V | SHT31-D | < 1 mA |
| 3.3 V | PCF8574 | < 100 µA (+ pull-up currents) |
| 12 V | LED strip, 1 m | 0.5–1.0 A |
| 12 V | Fan | 0.1–0.3 A |
| 24 V | Mist maker, 550 mL/h | **0.75 A** running, **1.3 A** inrush |

**Total worst case ≈ 24 W.** Size the PSU with ≥30 % headroom.

> The mist maker draws a **1.1–1.3 A transient for ~100 ms** while its
> oscillator acquires resonance ([MIST-MAKER.md §2.1](MIST-MAKER.md)). Size the
> 24 V rail for that, not for the 0.75 A running figure, or every mist cycle
> browns out whatever shares the supply.

### Recommended topology

The mist maker is **24 V DC**, confirmed — [MIST-MAKER.md](MIST-MAKER.md). It
contains a high-frequency inverter and will not run on 12 V, on 19 V, or on AC.

```
  24 V 3 A PSU ──┬──────────────────────────────► Mist maker (via MOSFET #1)
                 │
                 ├──[buck → 12 V]──┬────────────► LED strip (via MOSFET #3, PWM)
                 │                 └────────────► Fan (via MOSFET #2)
                 │
                 └──[buck → 3.3 V]──────────────► ESP-01 + SHT31-D + PCF8574
```

### Power rules

- **Never PWM the mist maker.** Its driver is an analog self-oscillating LC
  inverter that needs 50–200 ms of continuous DC to build its tank. Chopping the
  rail heats the transistor and prevents cavitation. Switch it on and off in
  seconds, not in duty cycle — see [AUTOMATION.md](AUTOMATION.md).
- Switch its **negative** lead with the N-channel MOSFET module.

- **Never power the ESP-01 from 5 V.** It is a 3.3 V part with no on-board regulator.
- **Never back-feed load current through the MCU rail.** Loads take their power
  from the PSU; the MCU only drives gates.
- Give the ESP-01 its own regulator output or a well-decoupled tap — WiFi TX
  bursts brown it out on a shared, sagging rail.
- Fit the bulk + ceramic caps on the 3.3 V rail near the ESP-01 **and** the
  PCF8574 (§6).

---

## 5. Output allocation — and the third-switch gap

There are **three switched loads** but the parts list has **two** XY-MOS modules.

| Output | Load | Switch | Driven from | Why |
|:--:|---|---|---|---|
| 1 | Mist maker | XY-MOS #1 | PCF8574 **P2** | Highest current, on/off only |
| 2 | Fan | XY-MOS #2 | PCF8574 **P3** | On/off only |
| 3 | LED strip | **needs a 3rd** | ESP-01 **GPIO3** | Must be **PWM** for the circadian dim curve |

**Options for the third switch:**

1. **Buy a third XY-MOS module** — simplest, identical wiring, PWM-capable. ✅ recommended
2. **Use a bare logic-level N-MOSFET** (IRLZ44N, AO3400) + 220 Ω gate resistor +
   10 kΩ gate pull-down. The LED strip is only ~1 A, so a 400 W module is overkill
   anyway — this is the cheap path.
3. **Drop dimming** and put the LED on PCF8574 P4 as plain on/off. You lose the
   sunrise/sunset curve; the moss and the snails only get a hard on/off photoperiod.

Nothing else in the build changes whichever you pick.

---

## 6. ⚠️ Driving MOSFET modules from the PCF8574 — read this

The PCF8574's outputs are **quasi-bidirectional**: they sink strongly (25 mA)
but source only **~100 µA** through a weak internal pull-up. An XY-MOS trigger
input has its own gate pull-down resistor. That pull-down against a 100 µA
source will **not** pull the gate to a valid logic HIGH — the MOSFET stays off,
or worse, sits half-on and cooks.

**Fix — one of:**

- **External pull-up (simplest):** fit a **4.7 kΩ resistor from each used PCF8574
  pin to 3.3 V**. The pin now idles HIGH strongly and pulls LOW hard. Verify with
  a multimeter that the trigger sees > 2.5 V when idle.
- **Verify with a scope/meter before connecting the load.** Measure the trigger
  voltage in both states with the module attached. If HIGH < 2.5 V, the pull-up
  is too weak — go lower (2.2 kΩ) or add a transistor buffer.

**Polarity:** the XY-MOS trigger is active-**HIGH** (HIGH = load on). The firmware
defaults to `RELAY_ACTIVE_LOW 1`. Either set `#define RELAY_ACTIVE_LOW 0` and
reflash, or leave it and tick **invert (NC)** on each output in the web UI —
whichever you do, **confirm the load is OFF at power-up before leaving it alone.**

**Decouple the PCF8574 — this matters.** The chip has *no reset pin*; any dip in
its VCC below the power-on-reset level silently reverts **all** outputs to HIGH
(0xFF) — which, with active-HIGH modules, turns **every load on at once**. Fit a
**0.1 µF ceramic across VCC↔GND right at the chip**, plus a **10–100 µF bulk cap**
on that rail, and keep VCC/GND on short soldered wire. The firmware re-asserts
the port every 250 ms (`pcfRefreshTask`) as a safety net, but that only shortens
the glitch — clean power is the real fix.

---

## 7. Wiring

### 7.1 ESP-01 pinout (antenna at top)

```
            ┌─────────────────┐
     GND ───┤ ●             ● ├─── VCC (3.3 V)
   GPIO2 ───┤ ●             ● ├─── RST
   GPIO0 ───┤ ●             ● ├─── CH_PD (EN)
RX/GPIO3 ───┤ ●             ● ├─── TX/GPIO1
            └─────────────────┘
```

### 7.2 Logic side

```
   3.3 V ──┬──[10 kΩ]── CH_PD (EN)
           ├──[10 kΩ]── RST            (optional, idle high)
           ├────────── ESP-01 VCC
           ├────────── SHT31-D VCC
           ├────────── PCF8574 VCC     (+ 0.1 µF at the chip, + 100 µF bulk)
           ├──[4.7 kΩ]─ SDA  (bus pull-up)
           └──[4.7 kΩ]─ SCL  (bus pull-up)

   GPIO0 (SDA) ──┬──► SHT31-D SDA
                 └──► PCF8574 SDA
   GPIO2 (SCL) ──┬──► SHT31-D SCL
                 └──► PCF8574 SCL

   PCF8574 A0/A1/A2 ──► GND            (address 0x20)

   GND ──┬── ESP-01 ─┬── SHT31-D ─┬── PCF8574 ─┬── MOSFET modules ─┬── PSU
         └───────────┴────────────┴────────────┴───────────────────┘
                          one common ground
```

### 7.3 Output side

```
   PCF8574 P2 ──[4.7 kΩ → 3.3 V pull-up]──► XY-MOS #1 SIG ──► Mist maker
   PCF8574 P3 ──[4.7 kΩ → 3.3 V pull-up]──► XY-MOS #2 SIG ──► Fan
   ESP-01 GPIO3 ──[220 Ω]──► MOSFET #3 gate ──► LED strip      (PWM)
                     └──[10 kΩ]── GND         (gate pull-down: strip OFF at boot)

   Each XY-MOS module:
      VIN+ / VIN−  ← from the PSU rail for that load
      OUT+ / OUT−  → the load
      SIG / GND    ← control from the PCF8574 (SIG) and common GND
```

The **gate pull-down on the LED channel is not optional** — without it GPIO3
floats during boot and the strip flashes on at full brightness every reset.

### 7.4 Inside vs. outside the tank

| Inside | Outside |
|---|---|
| SHT31-D (mid-height, away from the fogger plume and the LED) | ESP-01, PCF8574, all MOSFET modules |
| LED strip (**IP65+ sealed only**) | Mist maker chamber, module and reservoir |
| The fog hose, entering high | PSU and buck converters |

The mist maker does not sit in the tank. It runs in a printed chamber that holds
its water at a constant level and pipes the fog in through a 25 mm hose — parts,
print settings and assembly in **[cad/README.md](cad/README.md)**, and an
interactive model of it in **[cad/VIEWER.md](cad/VIEWER.md)**.

Everything outside lives in a ventilated enclosure. The inside of the tank is a
permanently condensing 90 %RH environment — unsealed electronics corrode in weeks.

**Sensor placement matters more than anything else in this section.** Mount the
SHT31-D at mid-height on a side wall, out of the direct fog stream and out of the
LED's radiated heat. A sensor in the plume reads 95 %RH while the far corner is
at 60 %, and the control loop chases a lie.

---

## 8. Flashing

The ESP-01 needs a **3.3 V logic** USB-serial adapter for the first flash only;
everything after that can go over OTA (`/update` or ArduinoOTA — needs 1 MB flash).

| USB-serial | → ESP-01 |
|---|---|
| 3.3 V | VCC **and** CH_PD (via 10 kΩ) |
| GND | GND |
| TX | ESP-01 RX (GPIO3) |
| RX | ESP-01 TX (GPIO1) |
| — | **GPIO0 → GND** to enter flash mode |

**Sequence:** GPIO0 to GND → power on / pulse RST → release GPIO0 → upload.
An "ESP-01 programmer" dongle with an auto-reset circuit does this for you.

Because the outputs are on the PCF8574, **TX/RX are free during flashing** — no
need to unplug the loads. Do disconnect the **LED MOSFET gate from GPIO3** while
flashing, since GPIO3 is the serial RX line.

---

## 9. I²C address reference

| Device | Address | Notes |
|---|---|---|
| SHT31-D | **0x44** (default) / 0x45 | ADDR pin; firmware auto-detects both |
| PCF8574 | **0x20**–0x27 | A0/A1/A2 jumpers; all-GND = 0x20 |
| PCF8574**A** | 0x38–0x3F | **Different chip variant** — the #1 cause of "outputs don't respond" |

0x44 and 0x20 never collide, so both devices live happily on the same two wires
with a single pair of pull-ups.

---

## 10. First-power-on checklist

1. ☐ All grounds tied together — ESP, sensor, expander, MOSFET modules, every PSU.
2. ☐ ESP-01 on **3.3 V** from a ≥500 mA regulator. Not 5 V. Not a shared sagging rail.
3. ☐ 4.7 kΩ pull-ups on SDA and SCL; 10 kΩ on CH_PD; GPIO0 **not** grounded.
4. ☐ 4.7 kΩ pull-ups on every used PCF8574 output pin (§6).
5. ☐ 0.1 µF at the PCF8574 + bulk cap on the 3.3 V rail (§6).
6. ☐ 10 kΩ gate pull-down on the LED MOSFET (§7.3).
7. ☐ **Loads disconnected.** Power up and measure the trigger voltages first.
8. ☐ Confirm every output reads OFF at rest, then connect the loads one at a time.
9. ☐ Mist chamber filled and its bottle fitted, level settled at **43.5–46 mm** —
        commissioning in [cad/README.md](cad/README.md).
10. ☐ Device makes a `ClimatePro-XXXX` hotspot → join it → set your WiFi.
11. ☐ Open `http://climate-pro.local` → sensor shows plausible numbers.
12. ☐ Toggle each output manually from the UI and confirm the right load responds.
13. ☐ Configure automation per [AUTOMATION.md](AUTOMATION.md), then run the tank
        empty for a week and read the 24 h history before adding animals.

### Troubleshooting

| Symptom | Cause |
|---|---|
| Sensor reads `--` / FAULT | SDA/SCL swapped, or missing 4.7 kΩ pull-ups |
| Outputs don't respond at all | Wrong `PCF_ADDR` — PCF8574A is 0x38, not 0x20 |
| Output on when it should be off | Polarity — flip `RELAY_ACTIVE_LOW` or the UI's invert flag |
| Outputs "blink" / one toggles another | PCF8574 brown-out — fit the decoupling caps (§6) |
| MOSFET warm but load barely runs | Gate not reaching full HIGH — pull-up too weak (§6) |
| LED flashes bright on every reset | Missing 10 kΩ gate pull-down on GPIO3 |
| ESP reboots when a load switches | PSU sag / no common ground / no bulk capacitance |

---

*If you move a wire, update the matching `#define` **and** this file, so
future-you isn't guessing.*

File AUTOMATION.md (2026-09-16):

# Automation & Climate Strategy

How the [Automated Snail Terrarium](README.md) actually regulates itself: what
each output does, the exact settings to enter in the Climate Panel Pro web UI,
and how to tune them from the 24 h history.

Read [HARDWARE.md](HARDWARE.md) first — this document assumes the wiring is done
and each output has been manually toggled and verified.

---

## 1. Control model

The firmware gives each output one of four control modes:

| Mode | Behaviour | Used here for |
|---|---|---|
| **Manual** | On/off from the dashboard | Commissioning, overrides |
| **Sensor** | Compares temp or humidity to a setpoint with a hysteresis dead-band | Mist maker, fan (humidity ceiling) |
| **Schedule** | Daily on/off clock times | Photoperiod (if not using the circadian channel) |
| **Interval** | Cyclic on for X, off for Y | Fan air-exchange pulses |

Layered on top of any mode:

- **Invert (NC)** — flips output polarity (see [HARDWARE.md §6](HARDWARE.md)).
- **Active-time window** — gates *any* mode to a time-of-day range. Use it to
  stop the mister running at night when the tank is already cool and near-saturated.
- **Minimum switch interval (anti-short-cycle)** — refuses to change state again
  until N seconds have passed. **Essential for the mist maker.**
- **Sensor-fault failsafe** — if the SHT31-D goes missing or fails CRC for 60 s,
  every automated output is forced **off**. A dead sensor must not mean an
  endlessly fogging tank.

---

## 2. Output configuration

Enter these in the web UI (Settings → Outputs). Values assume a temperate species
(*Cornu aspersum*) — adjust the temperature band for warmer species.

### Output 1 — Mist maker (humidity floor)

| Setting | Value |
|---|---|
| Name | `Mist maker` |
| Control mode | **Sensor** |
| Source | Humidity |
| Direction | **Below** setpoint |
| Setpoint | **78 %RH** |
| Hysteresis | **6 %** → on below 78 %, off at 84 % |
| Min switch interval | **300 s** (5 min) |
| Active window | **06:00 – 22:00** |

**Why:** the fogger is the only thing that raises humidity, so it tracks the
floor. The wide 6 % dead-band and the 5 min anti-short-cycle stop it from
chattering as the plume drifts past the sensor — an ultrasonic disc hates rapid
cycling, and short bursts fog the sensor without wetting the substrate.

The active window keeps it quiet overnight, when a sealed tank cools and rises
toward saturation on its own. If overnight humidity actually sags in your room,
widen the window.

### Output 2 — Fan (humidity ceiling + air exchange)

The fan does two jobs, and the firmware gives one mode per output. Pick the one
that matches the problem you actually have:

**Option A — humidity ceiling (start here):**

| Setting | Value |
|---|---|
| Name | `Fan` |
| Control mode | **Sensor** |
| Source | Humidity |
| Direction | **Above** setpoint |
| Setpoint | **90 %RH** |
| Hysteresis | **6 %** → on above 90 %, off at 84 % |
| Min switch interval | **120 s** |

**Option B — timed air exchange (if the tank goes stagnant but never hits 90 %):**

| Setting | Value |
|---|---|
| Control mode | **Interval** |
| On time | **3 min** |
| Off time | **90 min** |
| Active window | **06:00 – 22:00** |

**Best of both:** if you fit a third XY-MOS and a second fan — or split one fan
across two outputs is not possible — the cleanest answer is **Option A on Output 2**
plus a spare output on **Interval** driving the same fan through a diode-OR. In
practice, start with Option A and only add timed exchange if you see mould.

> The dead-bands are deliberately arranged so the mister (off at 84 %) and the
> fan (on at 90 %) **never fight each other**. Keep at least 4–6 % between them.

### Output 3 — LED strip (circadian light)

Configured under **Settings → Neon light**, not as a normal output:

| Setting | Value |
|---|---|
| Mode | **Auto** (circadian) |
| Sunrise | **07:00** |
| Sunset | **19:00** |
| Night level | **0 %** |
| Time zone | your local TZ |
| Channels | **1** (single warm-white) |

Brightness ramps sunrise → peaks at solar noon → eases to the night level after
sunset. Until the clock first syncs over NTP, Auto falls back to the manual
brightness value, so the light is never stuck off waiting for time.

**12 h photoperiod** suits both the moss and the snails. Snails are nocturnal —
they will do most of their moving after the lights drop, which is normal and not
a sign of a problem.

### Output 4 — spare

Leave PCF8574 **P4** free and wired. The obvious future addition is a small
heat mat on **Sensor / temperature / below 19 °C / 1.5 °C hysteresis** if the
room gets cold in winter.

---

## 3. Why these numbers

| Choice | Reasoning |
|---|---|
| Humidity floor **78 %**, ceiling **90 %** | Below ~70 % snails seal into their shells and stop eating; above ~95 % the tank grows mould and the substrate sours. 78–90 % sits comfortably inside that with room for sensor error. |
| Hysteresis **6 %** | Fogger plumes are locally saturated. A narrow band makes the output chatter every time the plume crosses the sensor. |
| Min switch **300 s** on the mister | Ultrasonic transducers degrade under rapid cycling, and a 10-second burst humidifies the air without ever reaching the substrate. Comfortably above the module's own 10 s on / 15 s off floor ([MIST-MAKER.md §2.2](MIST-MAKER.md)). |
| Mister window **06:00–22:00** | A sealed tank cools overnight and its RH climbs on its own. Misting into that just condenses on the glass. |
| Fan hysteresis arranged **below** the mister's off-point | Prevents the two outputs oscillating against each other — the classic humidifier/dehumidifier fight. |
| Photoperiod **12 h** | Enough for moss photosynthesis without pushing algae; matches a temperate seasonal midpoint. |
| Temperature **20–22 °C** | *Cornu aspersum* comfort band. Above ~26 °C is stressful, above 30 °C is dangerous. |

---

## 4. Commissioning: the empty-tank week

**Do not put animals in until this passes.** Set the tank up fully — substrate,
moss, hides, water dish — and run it empty for **7 days**.

| Day | What to check |
|:--:|---|
| 1 | Every output responds manually. Nothing is stuck on. Mister bottle full and the chamber level settled. |
| 1 | Sensor reads plausibly: room air ≈ 40–60 %RH before you close the lid. |
| 2–3 | Humidity settles inside 78–90 % and *stays* there without the mister running constantly. |
| 3 | No condensation film blocking your view of the whole front glass — that means over-misting. |
| 4–7 | Temperature stays 18–24 °C across the full day/night swing. |
| 7 | Read the **24 h history graph**: humidity should look like a shallow sawtooth, not a square wave or a flat line pinned at 95 %. |
| 7 | No mould on the substrate or hides. Any fuzz = increase fan time before adding snails. |
| 7 | Check the per-output **run-time counters**. A mister running > 2 h/day means the tank leaks humidity — improve the lid seal rather than misting harder. |

---

## 5. Tuning from the history graph

The 24 h graph tells you what to change:

| Pattern | Diagnosis | Fix |
|---|---|---|
| Humidity sawtooth is very **fast and shallow** | Hysteresis too narrow, or sensor in the fog plume | Widen hysteresis to 8 %; move the sensor away from the fogger |
| Humidity **pinned at 95 %+**, never falls | Not enough air exchange | Lower the fan setpoint to 88 %, or add the interval pulse |
| Humidity **sags every afternoon** | Room heating / LED warmth driving it off | Widen the mister's active window; check the lid seal |
| Mister runs **almost continuously** | Tank leaks humidity badly | Seal the lid; reduce ventilation holes; do **not** just raise the setpoint |
| Mister and fan **alternate rapidly** | Their dead-bands overlap | Push them apart: mister off at 84 %, fan on at 90 % |
| Temperature **spikes with the LED** | Strip is heating the tank | Lower peak brightness, or move the strip outside the glass |
| Humidity **flatlines** exactly | Sensor fault — check for the FAULT reading | Recheck I²C wiring and pull-ups ([HARDWARE.md §10](HARDWARE.md)) |

---

## 6. Failure modes worth designing against

| Failure | Consequence | Mitigation |
|---|---|---|
| Reservoir empties | Fog stops; humidity sags | The module has its own conductivity probe and shuts off at 41 mm, so it **cannot** burn out dry ([MIST-MAKER.md §3](MIST-MAKER.md)). Watch the humidity trend and the bottle, not the transducer. |
| Hard water scales the disc | Output halves within weeks, then the ceramic cracks | **Use RO or distilled water.** Descale in 50:50 white vinegar for 20–30 min when output drops |
| Mist maker PWM'd instead of switched | Driver overheats, no cavitation | Output mode must be Manual/Sensor/Interval — never the PWM channel. GPIO3 is the LED's, not the mister's |
| SHT31-D dies or drifts | Endless fogging or a bone-dry tank | Firmware failsafe forces outputs off after 60 s of fault — verify it by unplugging the sensor during commissioning |
| WiFi drops | — | Automation runs entirely on-device; WiFi is only for the dashboard. Nothing stops. |
| Power loss | Outputs off, tank coasts | A sealed 47 L tank holds its humidity for many hours. Settings persist in flash and reload on boot. |
| PCF8574 brown-out | **All outputs turn on at once** | Decoupling caps ([HARDWARE.md §6](HARDWARE.md)) + the firmware's 250 ms port refresh |
| Fan fails | Stagnant, mould | Weekly visual check; mould is visible long before it is dangerous |
| Over-misting | Sour substrate, drowned eggs | Watch the run-time counters, not just the instantaneous reading |

**Verify the failsafe during commissioning.** Unplug the SHT31-D with the mister
armed and confirm that after 60 s the output drops and the UI shows FAULT. This
is the single most important test in the whole build.

---

## 7. Routine maintenance

| Interval | Task |
|---|---|
| Daily | Glance at the dashboard: temp, humidity, output run-times |
| Weekly | Refill the mister's bottle; check for mould; feed and clean |
| Weekly | Confirm the sensor reading matches a second thermometer/hygrometer |
| Monthly | Wipe the ultrasonic disc (mineral scale kills output — use distilled water to slow it) |
| Monthly | Clear the fan of substrate dust |
| Quarterly | Re-check the 24 h history against the targets; re-tune if the room's season changed |
| Yearly | Replace the substrate; inspect the LED strip's seal for water ingress |

Using **distilled or deionised water** in the mist maker roughly triples the time
between descaling and keeps mineral dust off the moss.

---

*Setpoints here are a starting point, not gospel. Watch the animals: a snail that
stays sealed in its shell wants more humidity; one glued to the lid away from the
substrate usually wants less heat.*

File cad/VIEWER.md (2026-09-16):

# The 3D assembly viewer

An interactive model of the whole mister — printed parts, mist module, bottle,
fan, hose, cable and water — that you can orbit, pull apart and cut through in a
browser. It exists because the fits that matter here are between parts, and
those are the ones a still render hides.

Everything in it is generated from `params.scad`, so it cannot drift away from
what `verify.py` checks and what the printer gets.

---

## Quick start

```bash
cd cad
../.venv/bin/python viewer.py
```

That renders any out-of-date meshes, builds the page and serves it at
**http://127.0.0.1:8017/**. First run takes a couple of minutes because
OpenSCAD has twelve components to tessellate; after that it is instant.

Needs `openscad` on the PATH and the project's venv (`trimesh`, `numpy`).

### Options

| Flag | What it does |
|---|---|
| *(none)* | Build, then serve on `127.0.0.1:8017` |
| `--build` | Build `viewer/index.html` and stop |
| `--port N` | Serve on a different port |
| `--cdn` | Load three.js from a CDN instead of inlining it — 227 KB instead of 816 KB, but the page then needs a network |
| `--force` | Re-render every mesh, even ones that look current |

## Three ways to open it

1. **`viewer.py`** — builds and serves. The normal way.
2. **Straight off the disk.** `viewer.py --build`, then open
   `cad/viewer/index.html`. The page is one self-contained file — geometry,
   styles, script and three.js are all inlined — so it needs no server and
   no network. Nothing about it depends on being served over HTTP.
3. **On the web**, for a phone or to send to someone:
   **<https://snail-terrarium-mister.vercel.app>**. Deployed from `viewer/` — see *Deploying* below.

`viewer/index.html` is **committed**, not treated as build output. It is a
document of the project in its own right: it opens on any machine, years from
now, with no toolchain, no network and no OpenSCAD. The cost is that every
rebuild writes a fresh ~835 KB file into history — worth it for a page that
still works when nothing else does. `viewer/template.html` is its source.

If you only want a picture, five images rendered from the same model are
committed in `render/`; `viewer.py --stills` re-renders them.

## Deploying

```bash
../.venv/bin/python viewer.py --deploy
```

Builds, checks that `viewer/index.html` matches HEAD, then pushes. **Vercel
deploys from GitHub, not from your disk**: every push to `main` publishes
whatever `cad/viewer/` holds at that commit. So the committed page and the live
page are the same thing by construction, and the rebuild-before-deploy step is
there to stop you committing a stale one.

If the build changed `index.html`, `--deploy` stops and tells you to commit it
first. That is deliberate — pushing a page you have not committed is not
possible, and committing one you have not rebuilt is the mistake this catches.

The Vercel project is **snail-terrarium-mister** on the personal scope, with its
**Root Directory set to `cad/viewer`** and no framework, build step or server.
That setting is the whole configuration, and it is easy to get wrong: leave it
at the repository root and Vercel happily serves the repo, with no `index.html`
at `/` — a 404 on a deployment that reports as healthy.
`.vercelignore` keeps `template.html` out of the deployment, so the placeholder
version is never public.

Deploying by hand from `cad/viewer/` with `vercel deploy` no longer works, and
fails confusingly (`Root Directory "cad/viewer" does not exist`) because Vercel
applies the root directory on top of whatever you upload. Push instead. To
re-publish without a code change — after changing a project setting, say:

```bash
vercel redeploy snail-terrarium-mister.vercel.app
```

The production URL **<https://snail-terrarium-mister.vercel.app>** is public to
anyone with the link. The longer per-deployment and `-milads-projects-` URLs are
not: Vercel Authentication is on for the project, and they redirect to a Vercel
login. Share the short one.

---

## Controls

| | |
|---|---|
| **Orbit** | Drag |
| **Zoom** | Scroll |
| **Pan** | Right-drag, or shift-drag |
| **Explode** | Slider — 0 % assembled to 100 % fully apart |
| **Section** | Slider — sweeps a cutting plane through the model from "off" to just past the centre. Interior walls are drawn, so you see the bore, the water and the feed port in one view |
| **Show / hide a part** | Click it in the legend |
| **Spin** | Slow turntable. Honours `prefers-reduced-motion` |
| **Reset view** | Back to the default three-quarter |

Three parts appear and disappear on their own, because showing them otherwise
would be a lie:

- **Water** and the **cable route** only exist assembled, so they hide as soon
  as you start exploding.
- The **trim spacer** is an optional part you fit only if the level lands high,
  so it only appears once the model is pulled apart.

## The water-level gauge

The panel on the right is the one piece of the page that is not geometry. It
plots the module's own limits from [MIST-MAKER.md](../MIST-MAKER.md) against
where this design actually sits:

```
  50.0   chokes, spits drops instead of fogging
  47.0 ┐
       │ optimal band
  46.0 │ ← the feed port's apex: the level the design aims at
  43.5 │ ← where it really settles, 2.5 mm lower, because air has to
  42.0 ┘   bubble into the port before water can leave
  41.0   probe cuts the unit out
```

The whole settling range sits inside the optimal band with 2.5 mm of margin over
the probe. That is the reason the target is 46 and not the arithmetic middle of
the band — see **D21** in [DESIGN-DECISIONS.md](../DESIGN-DECISIONS.md).

The gauge is hidden below 1080 px wide, where there is no room for it.

---

## How it is built

```
  params.scad ──┬── mister.scad ────┐            the printed parts
                └── assembly.scad ──┤            the bought parts
                                    ▼
                          export_parts.scad      one component at a time
                                    │  openscad, per-part tessellation
                                    ▼
                        .build/parts/*.stl       12 meshes
                                    │  tools/pack_viewer.py
                                    ▼
                        one JSON blob, 207 KB    uint16 positions +
                                    │            index buffers, base64
                                    ▼
        viewer/template.html ──► viewer/index.html
                                    ▲
                    .build/three.min.js (cached, inlined)
```

`viewer.py` re-renders a mesh only when its `.stl` is older than `params.scad`,
`mister.scad`, `assembly.scad` or `export_parts.scad`. Change a dimension and
the next run rebuilds against it.

The figures in the title block — chamber size, mass, water level, wetted volume,
checks passed — are **not written into the template**. `verify.py` publishes them
to `.build/facts.json` on every run and `viewer.py` substitutes them, so the page
can only ever quote numbers that were actually verified. Build the viewer without
having run `verify.py` and they show as `?` rather than as something stale.

Positions are quantised to `uint16` against **one bounding box shared by every
part**, which is what keeps them in register with each other and turns 3 MB of
STL into a 207 KB blob. Geometry is de-indexed before normals are computed, so
the parts render flat-shaded: these are machined faces, not organic surfaces,
and smooth normals would round off every edge the design depends on.

---

## Changing it

**Add a part.** Give it a `PART ==` branch in `export_parts.scad`, then a row in
`PARTS` in `tools/pack_viewer.py` (name, label, colour, opacity, explode vector,
group) and in `COMPONENTS` in `viewer.py` (name, `$fa`, `$fs`). The legend
builds itself from that list.

**Move something in the explode.** Edit its explode vector in
`tools/pack_viewer.py`. The vector is in **OpenSCAD coordinates** — the page
rotates the whole model Z-up-to-Y-up once, so you never think in three.js axes.

**Smoother or lighter meshes.** `COMPONENTS` in `viewer.py` carries `$fa` and
`$fs` per part. Most run at `$fa=5, $fs=1.0`; the hose is a chain of hulled
spheres and gets expensive fast, so it runs at `$fa=12, $fs=3.0`. Then
`--force`.

**Colours and layout** live in `viewer/template.html` as CSS custom properties,
with light and dark palettes defined token-by-token. Part colours come from
`pack_viewer.py` so the 3D and the legend swatches cannot disagree.

---

## Troubleshooting

| | |
|---|---|
| **Blank stage, page otherwise fine** | WebGL is off or blocked. Check `chrome://gpu`, or try another browser |
| **`missing .../parts/x.stl`** | Run `viewer.py` rather than `pack_viewer.py` directly — `viewer.py` is what exports the meshes |
| **`openscad failed on <part>`** | The CAD does not compile. Run `verify.py`, which reports properly |
| **Geometry looks stale after an edit** | `viewer.py --force` |
| **`could not fetch three.js`** | No network on first build. It is cached at `.build/three.min.js` afterwards; copy one in by hand if you need to |
| **Page is 816 KB** | That is three.js inlined, and it is why the file works offline. Use `--cdn` for 227 KB |
| **Port already in use** | `--port 8018` |

## Why these choices

**three.js r128, pinned and inlined.** Pinned because an unpinned CDN version
silently changes API under a page nobody is watching. Inlined because a viewer
that needs a network to open is not much use next to a printer.

**A clipping plane instead of an OpenSCAD section.** OpenSCAD paints every cut
face in the colour scheme's cutout colour no matter what `color()` says, and a
full `--render` discards per-part colours altogether. Capping the cut with a real
`projection()` cross-section fixes both but costs a CGAL render per part, which
runs into minutes. WebGL clips per fragment, in colour, live.

**One template for both the offline page and the `--cdn` build**, so the two
cannot drift apart. The only difference is whether three.js is inlined or linked.

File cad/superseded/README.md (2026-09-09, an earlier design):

# Superseded

All of these were drawn against a module height that turned out to be wrong.

The vendor spec reads "Ø45 x 45 mm", which I first took as a cube, then — from
photographs — as a ~29 mm body plus a removable cap. **Both were wrong. The
module is 45 mm tall.**

That single number invalidates every part in here, because each hangs a Mariotte
standpipe *inside* the chamber beside the module. With a Ø45 module that is also
45 mm tall, and the water held at 44 mm, a standpipe alongside it needs a **Ø80
bore** to clear — nearly double what these were drawn for, and the wall area
scales with the square.

The replacement runs the feed **outside** the chamber wall, entering through a
port at the water line, which keeps the bore at Ø60.

Kept for reference only. Do not print.

---

## Second wave: the first bottle-fed body

`mister_section.scad`, `gasket.scad` and `cap_chamber.scad` joined them later,
for different reasons:

- **`gasket.scad`** — the TPU neck washer. Replaced by the captured PET cap,
  whose own liner does the sealing. That is what a bottle cap liner is *for*.
- **`cap_chamber.scad`** — an alternative two-part cup-and-top arrangement,
  never built. It still hangs a standpipe inside beside the module, so it has
  the same Ø80 problem as everything else here.
- **`mister_section.scad`** — sectioned the *STL files* rather than the model,
  so it showed whatever was last exported instead of what the source says.
  Replaced by `../section2d.scad`, which sections the real solids.

The body those were drawn against was itself replaced after a boolean audit
found eight defects in it, three of them fatal — see **D15** in
[../../DESIGN-DECISIONS.md](../../DESIGN-DECISIONS.md). Retired parameters those
files still need live in `legacy_params.scad`, so they open and render, but
nothing here is current.

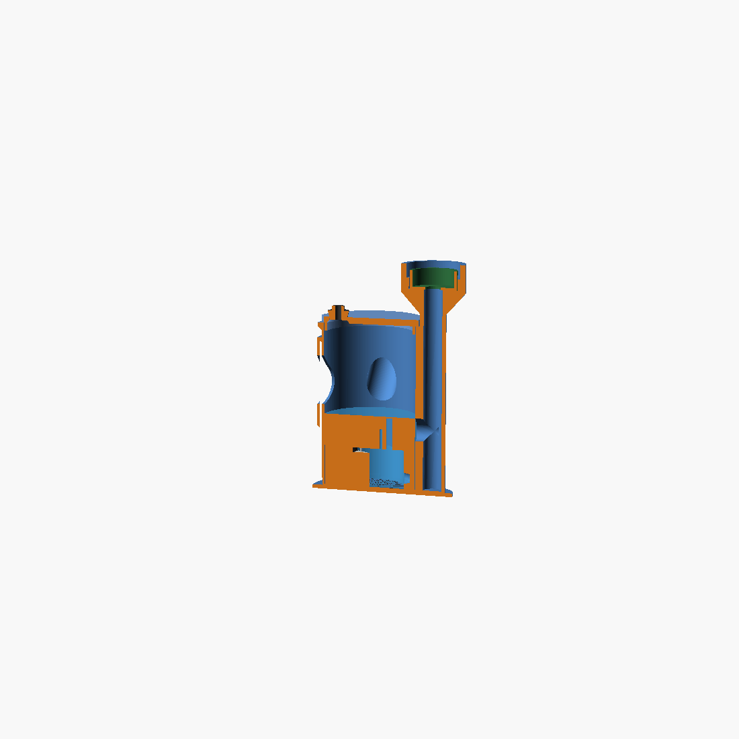
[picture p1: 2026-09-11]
cad/render/section.png

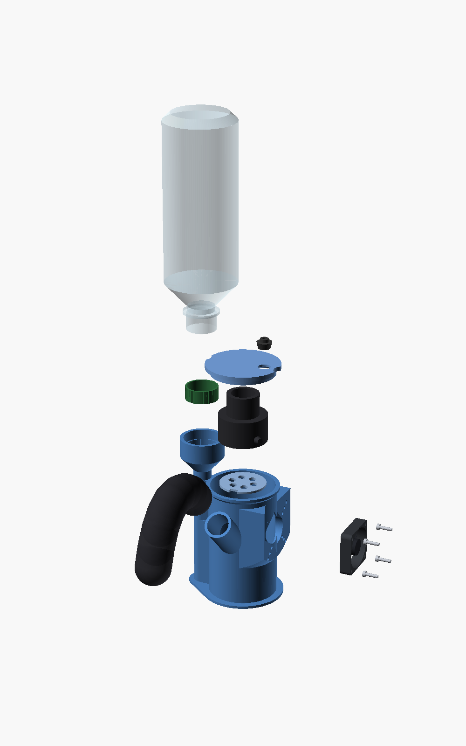
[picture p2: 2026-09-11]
cad/render/exploded.png

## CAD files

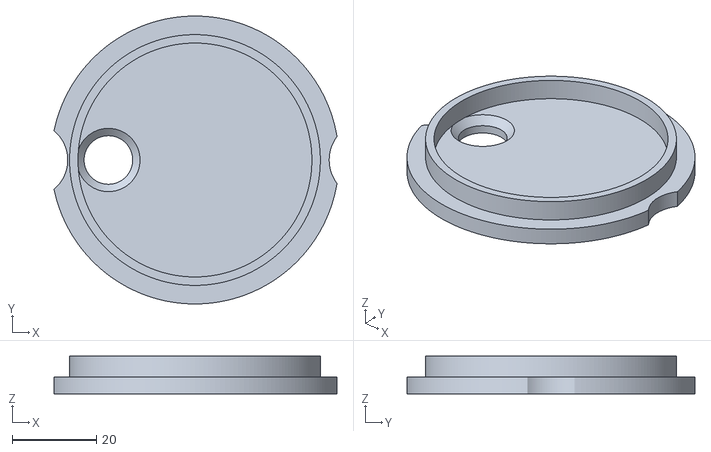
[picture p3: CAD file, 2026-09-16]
cad/stl/mister_lid.stl
67.0 x 68.2 x 9.00

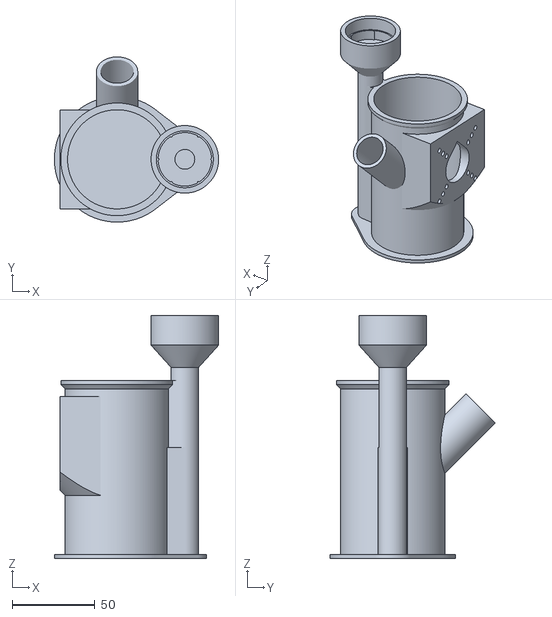
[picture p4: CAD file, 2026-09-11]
cad/stl/mister_body.stl
99.5 x 100.0 x 147.1

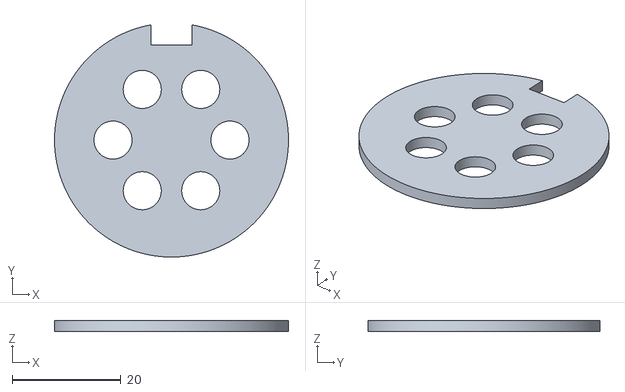
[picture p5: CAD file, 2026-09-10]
cad/stl/mister_spacer.stl
43.0 x 42.7 x 2.00

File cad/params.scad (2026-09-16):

// ─────────────────────────────────────────────────────────────
//  Automated Snail Terrarium — shared parameters
//  Change a number, run ../.venv/bin/python verify.py, get STLs.
//
//  Every dimension here is either MEASURED, taken from
//  MIST-MAKER.md, or DERIVED from those. Nothing is guessed.
//  Anything still to be confirmed says MEASURE.
// ─────────────────────────────────────────────────────────────

// ── Mist maker module ────────────────────────────────────────
// Source: MIST-MAKER.md (ECA 3791 / CL-24 class, 550 mL/h).
// The module is ONE potted assembly, Ø45 x 45 mm, with a fixed
// splash collar. It has no removable cap: the earlier "cap ON /
// cap OFF" pair of water levels described a part that does not
// exist, and both are gone.
//
// Depths are TOTAL WATER DEPTH measured from the surface the
// module stands on, which is the chamber floor:
//   41      probe closes, unit starts
//   42-47   optimal - 20-25 mm of water over the recessed disc
//   >50     hydrostatic head damps cavitation; throws droplets
// The module carries its own conductivity probe, so it CANNOT
// run dry. Every dry-run guard in the earlier designs was
// solving a problem the hardware had already solved.
mm_module_od      = 45;
mm_module_h       = 45;
mm_cable_od       = 3.8;
// The cable ships with a sliding conical rubber bung, meant to
// seal against a chamfered hole. The lid uses it - see LID.
bung_d_max        = 14.0;
bung_d_min        = 11.0;

water_probe       = 41;    // below this the unit shuts off
water_lo          = 42;    // optimal band, lower
water_hi          = 47;    // optimal band, upper
water_choke       = 50;    // above this it splatters instead of fogging

// ── Water level ──────────────────────────────────────────────
// The level is set by ONE feed port, positioned by its APEX: the
// siphon stabilises where air can just get in, which is the top
// of the opening, not its centre.
//
// Park it in the MIDDLE of the optimal band, not at an edge. The
// port is a printed feature and the Mariotte meniscus adds a
// millimetre or two of its own, so the target needs margin on
// both sides:
//   46.0 mm  ->  5.0 mm over the probe, 4.0 mm under splashing
// and air has to bubble INTO the port to let water out, which costs
// ~2.5 mm of head on a Ø12 port, so the level actually settles
// somewhere around 43.5-46.0. That whole range is inside the band,
// and the low end still clears the probe by 2.5 mm. Targeting the
// arithmetic centre of the band instead put the low end at 42.0,
// which is 1.0 mm off shutting the unit down.
// Earlier revisions held 47 mm, which is the top of the band and
// 3 mm from choking - no margin at all in the direction that
// actually stops the fog.
water_hold        = 46.0;
// Optional trim: a printed disc under the module raises it,
// which is the same as lowering the water. Fit it only if the
// real level lands high (visible splashing, coarse droplets).
trim_spacer_t     = 2.0;
trim_spacer_d     = 43;    // inside the module footprint

// ── Chamber ──────────────────────────────────────────────────
// Cylindrical: least wall for a given volume, and the fog plume
// is round anyway.
ch_id             = 60;    // Ø45 module + 7.5 mm annulus for fog and feed
ch_wall           = 1.6;   // EXACTLY 4 perimeters at a 0.4 mm nozzle, so the
                           // wall is 100% shell with no infill inside it.
                           // A thicker wall is WORSE unless it is also a
                           // multiple of 0.4: at 2 perimeters a 2.0 mm wall
                           // is 0.8 mm shell + 1.2 mm of 20% infill, which
                           // weeps. Keep this a multiple of 0.4.
ch_od             = ch_id + 2*ch_wall;
ch_floor          = 3.2;   // 8 perimeters' worth. This is the largest flat
                           // face under water; it is not the place to save
                           // 0.8 mm.

// Locating lugs for the module, INSIDE the chamber and standing
// UP from the floor. The previous revision cut a Ø46.5 pocket
// into the UNDERSIDE of the floor instead, which located nothing
// and left a 0.9 mm membrane holding the water.
// Gaps between the lugs let the module's cable exit at any angle.
lug_id            = 47.5;  // 1.25 mm clearance per side on a Ø45 module
lug_w             = 2.0;
lug_h             = 2.5;
lug_n             = 4;
lug_arc           = 42;    // degrees of each lug; the rest is gap

// Rim flange. A 1.6 mm wall is too narrow a ledge for the lid, so
// thicken the top few mm. The step out to the flange is a 45°
// CONE, not a square ledge: a 2.5 mm horizontal overhang running
// right round the part droops on every printer.
ch_flange_w       = 2.5;
ch_flange_od      = ch_od + 2*ch_flange_w;
ch_flange_cham    = ch_flange_w;          // 45°
ch_flange_h       = ch_flange_cham + 2.5;

// ── Fog outlet and fan ───────────────────────────────────────
// Air in through the fan, fog out through the nozzle, in series.
// The INLET must be the larger of the two or it throttles the
// outlet, so the fan bore is sized above the nozzle bore.
duct_clear        = 6.0;   // clear air under the lowest duct opening
// Sized around a hose you can actually buy: the spigot OD is the
// hose's ID, so nozzle_d is what is left after the wall.
nozzle_hose_id    = 25;    // standard 25 mm ID pond/aquarium hose
hose_engage       = 15;    // clear spigot the hose must be able to sit on:
                           // 0.6x the bore, enough to clamp behind
hose_wall         = 3.0;   // a 25 mm ID hose is about this thick, and it is
                           // the hose's OUTER BACK CORNER that fouls the
                           // barrel first - not its bore
nozzle_wall       = 2.5;
nozzle_d          = nozzle_hose_id - 2*nozzle_wall;   // Ø20 fog bore
// TILTED 45° UP, and that is not styling. A teardrop fixes a
// horizontal HOLE, because the material above it can be shaped.
// It cannot fix a horizontal PROTRUSION: the underside of a round
// spigot sticking out of a wall is a 90° overhang whatever its
// cross-section, and cutting it back to 45° leaves a V that no
// hose will seal on. An inclined cylinder has no such problem -
// every normal on its underside sits at exactly the tilt angle -
// so at 45° the whole spigot, bore included, is self-supporting
// and still perfectly round for the hose.
// Fog rises into it, and condensate runs back down into the
// chamber instead of dripping out of the hose.
nozzle_tilt       = 45;
fan_bore          = 26;    // > nozzle_d: inlet must not throttle the outlet
// One pad, drilled for BOTH 30 mm (24 mm pitch) and 40 mm (32 mm
// pitch) fans, because what is in stock varies. The screw holes
// are BLIND in the pad and must never reach the chamber: the
// previous revision ran them 12 mm deep, straight through the
// wall and into the water.
fan_pad_t         = 3.0;
// Three bolt patterns, because which fan actually does the job through
// a Ø26 bore is a question you answer by trying them. Diameter is not
// what decides it - everything goes through the same bore and out the
// same Ø20 nozzle, so the fan's STATIC PRESSURE matters and its airflow
// rating does not. A 30 mm at 12 V can beat a 50 mm at 5 V here.
//
// 25 mm fans (20 mm pitch) are deliberately NOT drilled: the barrel
// curves closest to the pad at narrow pitches, and a 5 mm screw there
// leaves 1.3 mm of wall against the 1.6 mm limit. 60 mm and up cannot
// work at all - the pad would wrap past the barrel and push ch_h up.
fan_pitch_30      = 24;
fan_pitch_40      = 32;
fan_pitch_50      = 40;
fan_pitch_max     = max(fan_pitch_30, fan_pitch_40, fan_pitch_50);
fan_pitch_min     = min(fan_pitch_30, fan_pitch_40, fan_pitch_50);
fan_screw_d       = 3.2;
// The pad's flat face does NOT begin at its bottom edge. The 45°
// chamfer under it - which is there so the underside is not the one
// horizontal ceiling on the part - eats into that face from below,
// and by more the further out you go in y: the face only exists once
// the cone has grown past sqrt((ch_od/2 + fan_pad_t)^2 + y^2).
//
// At 42 mm the pad lost 3.0 mm of face at the centreline and 6.5 mm
// at the 40 mm fan's bolt circle, which put its lower two screws
// 1.75 mm ONTO the chamfer. They had no flat seat: a gap under the
// fan and two screws loaded in bending. So the height is derived
// from the widest pattern the pad claims to take, not picked.
fan_seat          = 1.6;   // flat all round a screw before the chamfer
fan_face_r        = sqrt(pow(ch_od/2 + fan_pad_t, 2) + pow(fan_pitch_max/2, 2));
fan_pad           = fan_pitch_max + 2*fan_seat + 2*(fan_face_r - ch_od/2);
// 5 mm, not 8: at the 24 mm bolt pitch the barrel wall is closest to
// the pad, and a deeper hole comes out inside the water.
fan_screw_depth   = 5.0;
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

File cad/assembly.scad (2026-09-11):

// ─────────────────────────────────────────────────────────────
//  ASSEMBLY — for looking at, not for printing.
//
//  Everything here is driven from params.scad and mister.scad, so
//  it cannot drift away from the parts that actually get printed:
//  change a dimension and this picture changes with it.
//
//  The bought parts are modelled from their own documentation --
//  the mist module from MIST-MAKER.md §4, the bottle as a standard
//  0.5 L PET finish -- so the fits you see are the real fits.
//
//    EXPLODE  0 = assembled, 1 = fully apart
//    SECTION  1 = cut the near half away
//    BOTTLE   0 = leave the reservoir off (it is 190 mm of the height)
//
//  Renders:
//    openscad -o out.png --imgsize=1200,1600 --camera=... assembly.scad
// ─────────────────────────────────────────────────────────────
include <params.scad>
use <mister.scad>

EXPLODE = 0;     // 0 .. 1
SECTION = 0;
BOTTLE  = 1;
$fa = 3; $fs = 0.6;

E = EXPLODE;

// ── colours ──────────────────────────────────────────────────
PRINTED  = "#4a7ebb";      // PETG
PRINTED2 = "#6f9ad3";
POTTING  = "#2c2c30";      // the module's black epoxy
CERAMIC  = "#d8d2c0";
METAL    = "#b8bcc4";
PET      = [0.80, 0.88, 0.92, 0.35];
WATER    = [0.25, 0.62, 0.85, 0.45];
RUBBER   = "#3a3a3a";
FANBODY  = "#35383d";

// ─────────────────────────────────────────────────────────────
//  BOUGHT PARTS
// ─────────────────────────────────────────────────────────────

// Mist module, per MIST-MAKER.md §4: Ø45 x 45, a 25 mm potted base
// carrying a 20 mm splash collar, with the Ø20 ceramic disc
// recessed in the well 22 mm above the base and the conductivity
// probe standing beside it.
mm_base_h    = 25;
mm_collar_d  = 30;
mm_well_d    = 22;
mm_disc_z    = 22;

module mist_module() {
    color(POTTING) {
        difference() {
            union() {
                cylinder(d = mm_module_od, h = mm_base_h);
                translate([0, 0, mm_base_h - eps])
                    cylinder(d = mm_collar_d, h = mm_module_h - mm_base_h + eps);
            }
            translate([0, 0, mm_disc_z])
                cylinder(d = mm_well_d, h = mm_module_h);
        }
        // strain relief where the cable leaves the side
        translate([mm_module_od/2 - 3, 0, 7]) rotate([0, 90, 0])
            cylinder(d1 = 9, d2 = 5.5, h = 7);
    }
    color(CERAMIC) translate([0, 0, mm_disc_z - 0.9])
        cylinder(d = 20, h = 1.0);
    color(METAL)   translate([7.5, 0, mm_disc_z])
        cylinder(d = 1.6, h = 16);            // conductivity probe
}

// 1.4 m of UL2464, Ø3.8. Drawn as the run it actually takes: out of
// the module, up the inside of the chamber and out through the lid.
module cable() {
    pts = [[mm_module_od/2 + 3, 0, ch_floor + 7],
           [ch_id/2 - 4,        0, ch_floor + 9],
           [ch_id/2 - 4,        2, ch_floor + 34],
           [-cable_hole_r + 3,  1, ch_h - 16],
           [-cable_hole_r,      0, ch_h + lid_t + 4],
           [-cable_hole_r,      0, ch_h + lid_t + 26]];
    color(RUBBER) for (i = [0 : len(pts) - 2])
        hull() {
            translate(pts[i])     sphere(d = mm_cable_od);
            translate(pts[i + 1]) sphere(d = mm_cable_od);
        }
}

// The conical bung the cable ships with, seated in the lid's
// countersink. This is why the cable leaves through the lid.
module bung() {
    color(RUBBER) difference() {
        union() {
            cylinder(d1 = bung_d_min, d2 = bung_d_max, h = 6);
            translate([0, 0, 6 - eps]) cylinder(d = 8, h = 3);
        }
        translate([0, 0, -eps]) cylinder(d = mm_cable_od, h = 12);
    }
}

// Standard PET cap, captured in the socket and drilled through.
// It sits closed-face DOWN on the pocket floor, threads up, so the
// bottle's own liner does the sealing.
module bottle_cap() {
    color("#2f6f3f") difference() {
        cylinder(d = cap_od, h = cap_h);
        translate([0, 0, cap_floor_t])
            cylinder(d = cap_od - 3.6, h = cap_h);
        translate([0, 0, -eps])
            cylinder(d = 10, h = cap_floor_t + 2);         // the hole you drill
        for (i = [0 : 59]) rotate([0, 0, i*6])             // knurl
            translate([cap_od/2, 0, -eps]) cylinder(d = 0.8, h = cap_h + 2*eps);
    }
}

// 0.5 L PET bottle, inverted. Neck finish, support ring, shoulder,
// body. Its mouth seats inside the captured cap.
module bottle() {
    body_h = bottle_ml * 1000 / (PI/4 * bottle_body_d*bottle_body_d);
    // Neck finish from the params, so the drawing and the harness
    // cannot disagree about the ring that has to clear the socket.
    ring_z = neck_ring_h;
    sh_z   = ring_z + 2.5 + 4.5;
    color(PET) {
        cylinder(d = 27.4, h = ring_z);                       // threaded neck
        translate([0, 0, ring_z])
            cylinder(d = neck_ring_d, h = 2.5);               // support ring
        translate([0, 0, ring_z + 2.5]) cylinder(d = 25, h = 4.5);
        translate([0, 0, sh_z])
            cylinder(d1 = 25, d2 = bottle_body_d, h = bottle_shoulder);
        translate([0, 0, sh_z + bottle_shoulder])
            cylinder(d = bottle_body_d, h = body_h);
        translate([0, 0, sh_z + bottle_shoulder + body_h - eps])
            cylinder(d1 = bottle_body_d, d2 = bottle_body_d - 14, h = 7);
    }
}

// 40 mm fan, blowing INTO the chamber.
module fan40() {
    color(FANBODY) difference() {
        hull() for (x = [-1, 1], y = [-1, 1])
            translate([x*16, y*16, 0]) cylinder(r = 4, h = 10);
        translate([0, 0, -eps]) cylinder(d = 38, h = 10 + 2*eps);
        for (x = [-1, 1], y = [-1, 1])
            translate([x*fan_pitch_40/2, y*fan_pitch_40/2, -eps])
                cylinder(d = 3.4, h = 12);
    }
    color("#22242a") {
        cylinder(d = 15, h = 9);
        for (i = [0 : 6]) rotate([0, 0, i*360/7])
            translate([0, 0, 2]) rotate([12, 0, 0])
                translate([6, 0, 0]) cube([12, 1.2, 5], center = true);
    }
}

module m3_screw(len) {
    color(METAL) {
        cylinder(d = 3, h = len);
        translate([0, 0, len - 2.4]) cylinder(d = 5.5, h = 2.4);
    }
}

// Ø25 ID fog hose, swept along the path it really takes: off the
// 45° nozzle, over, and DOWNHILL to the tank so condensate drains
// forward instead of back into the chamber.
module hose() {
    a  = nozzle_tilt;
    s0 = ch_od/2/cos(a) + nozzle_len - 3;      // distance ALONG the tilted axis
    p0 = [0, s0*cos(a), nozzle_axis_z + s0*sin(a)];
    // a few control points, then resampled so the hull chain is smooth
    k   = [[0,0], [8,8], [18,14], [30,17], [42,16], [54,10], [64,0], [72,-14],
           [78,-30]];
    pts = [for (i = [0 : len(k) - 1]) p0 + [0, k[i][0], k[i][1]]];
    color([0.15, 0.15, 0.17, 0.85])
        for (i = [0 : len(pts) - 2]) hull() {
            translate(pts[i])     sphere(d = nozzle_od + 6);
            translate(pts[i + 1]) sphere(d = nozzle_od + 6);
        }
}

// What the chamber actually holds, with the module displacing it.
module water() {
    difference() {
        translate([0, 0, ch_floor]) cylinder(d = ch_id - 0.6, h = water_hold);
        translate([0, 0, ch_floor - eps]) mist_module();
        translate([0, 0, ch_floor - eps]) cylinder(d = mm_module_od, h = mm_base_h);
    }
}

// ─────────────────────────────────────────────────────────────
//  THE ASSEMBLY
// ─────────────────────────────────────────────────────────────
// Section each part INSIDE its own color(), so the cut faces take that
// colour instead of OpenCSG's default. Cutting the whole assembly with one
// difference() paints every cut face the same warning orange, and a full
// --render throws the colours away altogether.
module sect() {
    if (SECTION) {
        difference() {
            children();
            translate([-200, -400, -20]) cube([400, 400, 600]);
        }
        // Cut faces come out in the colour scheme's cutout colour, not the
        // part's. Capping them with a real projection() cross-section looks
        // better but costs a CGAL render per part, which is minutes.
    } else children();
}

module assembly() {
    // printed chamber
    color(PRINTED) sect() body();

    // module, standing on the floor inside the locating lugs
    translate([0, 0, ch_floor + E*150]) rotate([0, 0, 150]) sect() mist_module();
    if (E < 0.02) color(WATER) sect() water();

    // lid, lifted straight up
    translate([0, 0, ch_h + E*115]) color(PRINTED2) sect() lid();
    translate([-cable_hole_r, 0, ch_h + lid_t - 2 + E*135]) sect() bung();
    if (E < 0.02 && !SECTION) cable();

    // captured cap and the bottle screwed into it
    translate([feed_centre, 0, pocket_z + E*55]) sect() bottle_cap();
    if (BOTTLE)
        translate([feed_centre, 0, pocket_z + 2 + E*120]) sect() bottle();
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

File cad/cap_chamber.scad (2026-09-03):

// Bottle-fed cap chamber (the Thingiverse/MakerWorld approach), sized
// for THIS module rather than a 20 mm disc. Two parts: a cup the module
// drops into, and a top carrying the bottle socket + standpipe.
include <params.scad>
cc_id    = 58;                       // module 45 + fog clearance
cc_wall  = 1.6;
cc_od    = cc_id + 2*cc_wall;
cc_water = mm_module_h + 25;         // 70 mm: level the bottle mouth holds
cc_head  = 40;                       // fog headspace
cc_h     = cc_water + cc_head;
cc_flange= 3;

module cup() {
    difference() {
        union() {
            cylinder(d = cc_od, h = ch_floor + cc_h);
            translate([0,0,ch_floor + cc_h - 4])
                cylinder(d = cc_od + 2*cc_flange, h = 4);
        }
        translate([0,0,ch_floor]) cylinder(d = cc_id, h = cc_h + eps);
        translate([-cable_notch_w/2, -cc_od/2 - cc_flange - eps,
                   ch_floor + cc_h - cable_notch_h])
            cube([cable_notch_w, cc_flange + cc_wall + 2*eps, cable_notch_h + eps]);
    }
}
module top() {
    sp_len = cc_h - cc_water;
    difference() {
        union() {
            cylinder(d = cc_od + 2*cc_flange, h = plate_t);
            translate([0,0,-lid_spigot_h]) cylinder(d = cc_id - 2*lid_fit, h = lid_spigot_h);
            translate([12,0,-sp_len]) cylinder(d = sp_od, h = sp_len + plate_t);
            translate([-16,0,plate_t-eps])
                cylinder(d = fog_port_d + 2*fog_boss_wall, h = fog_collar_h);
        }
        translate([12,0,-sp_len-eps]) cylinder(d = sp_bore, h = sp_len + plate_t + 2*eps);
        translate([-16,0,-lid_spigot_h-eps])
            cylinder(d = fog_port_d, h = lid_spigot_h + plate_t + fog_collar_h + 2*eps);
        for (a=[70,110,250,290]) rotate([0,0,a]) translate([22,0,-lid_spigot_h-eps])
            cylinder(d = vl_vent_d, h = lid_spigot_h + plate_t + 2*eps);
    }
}
if (PART == "cup") cup(); else top();

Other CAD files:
cad/chamber.scad
cad/check.scad
cad/checks.scad
cad/export_parts.scad
cad/gasket.scad
cad/lid.scad
cad/mister.scad
cad/mister_section.scad
cad/section.scad
cad/section2d.scad
cad/superseded/cap_chamber.scad
cad/superseded/chamber.scad
cad/superseded/check.scad
cad/superseded/gasket.scad
cad/superseded/legacy_params.scad
cad/superseded/lid.scad
cad/superseded/mister_section.scad
cad/superseded/section.scad
cad/superseded/vessel_lid.scad
cad/superseded/vessel_section.scad
cad/vessel_lid.scad
cad/vessel_section.scad

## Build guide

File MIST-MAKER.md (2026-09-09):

# Ultrasonic Mist Maker (550 mL/h) — Technical Datasheet & Integration Guide

Technical specification, electrical characteristics, hydrological operating limits, and control guidelines for the **550 mL/h Ultrasonic Mist Maker / Atomizer Module** sourced from ECA.

- **Vendor Listing:** [ECA E-Shop (ماژول تولید بخار سرد اولتراسونیک اتومیزر 550ml در ساعت)](https://eshop.eca.ir/%D9%85%D8%A7%DA%98%D9%88%D9%84-%D9%88-%D8%B3%D9%86%D8%B3%D9%88%D8%B1-%D8%A8%D8%AE%D8%A7%D8%B1-%D8%B3%D8%B1%D8%AF/3791-%D9%85%D8%A7%DA%98%D9%88%D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)
- **ECA Product ID / SKU:** `3791`
- **PrestaShop Reference Code:** `3011018004`
- **OEM Platform Equivalents:** CL-24 / DK-24 / MY-011 / M011 (Single-head 45 mm submersible atomizer, plastic housing, no LED)

---

## 1. Quick Reference

| Parameter | Confirmed Value | Tolerance / Range |
|---|---|---|
| **Operating Voltage** | **24.0 V DC** | 22.0 V – 26.0 V DC |
| **Running Current** | **0.75 A** | 0.70 A – 0.85 A (at 24 V, 25 °C water) |
| **Power Consumption** | **~18 W – 20 W** | 24 W maximum rating |
| **Inrush / Startup Current** | **~1.1 A – 1.3 A** | Transient peak during resonance acquisition (~100 ms) |
| **Oscillation Frequency** | **1.70 MHz** | ±40 kHz (1700 kHz bulk acoustic resonance) |
| **Transducer Disc** | **Ø20.0 mm ceramic PZT** | Lead Zirconate Titanate, recessed well mount |
| **Mist Output Rate** | **≥ 450 – 550 mL/h** | Measured with optimal 20–25 mm head above disc at 25 °C |
| **Aerosol Droplet Size** | **1.0 – 5.0 µm** | Sub-micron to fine cold aerosol |
| **Water Operating Temp** | **+5 °C to +45 °C** | Optimal: +20 °C to +30 °C |
| **Dry-Run Protection** | **Integrated conductive probe** | Cuts oscillation when water drops below probe tip |
| **Probe Trigger Level** | **41 mm from vessel base** | Minimum total vessel water depth to start |
| **Optimal Liquid Depth** | **42 mm – 47 mm from base** | ~20 mm – 25 mm liquid column over the recessed disc |
| **Choking Depth** | **> 50 mm from base** | Acoustic energy suppressed; splatters large droplets |
| **Housing Dimensions** | **Ø45.0 mm × 45.0 mm H** | Cylindrical body with central splash-guard collar |
| **Cable Specification** | **1.4 m (1400 ± 20 mm)** | UL2464 24 AWG × 2C, OD 3.8 mm, with sliding rubber bung |
| **Power Connector** | **5.5 × 2.1 mm DC barrel jack** | Female socket, **Center Positive (+)**, **Sleeve GND (-)** |
| **Ingress Protection** | **IP68** (Submersible) | Lower body factory potted in solid black epoxy resin |
| **Total Weight** | **96 g** | Module body, cable, and connector combined |

---

## 2. Electrical Characteristics & Power Integration

### 2.1 Voltage & Polarity
- **Input Type:** Direct Current (**DC only**).
  > **Note:** Some legacy industrial foggers run on 24 V AC via bare step-down transformers. **This unit requires regulated 24 V DC.** It contains an internal high-frequency inverter circuit and will not run on 12 V, 19 V, or AC without internal damage or failure to oscillate.
- **DC Jack Pinout:** Standard 5.5 mm outer diameter, 2.1 mm center pin.
  - **Center Pin:** `+24 V DC`
  - **Outer Sleeve:** `GND (0 V)`
- **PSU Sizing:** Size the dedicated 24 V power supply for **≥ 1.5 A** for a single unit, or **3.0 A** if running buck converters from the same supply to feed 12 V fans and 3.3 V logic rails.

### 2.2 Microcontroller & MOSFET Switching Rules
- **Switching Topology:** Switch the negative lead (`GND`) using a logic-level N-channel MOSFET module (e.g. *XY-MOS 400 W dual N-channel module*, *AO3400*, *IRLZ44N*), or use a relay / high-side P-channel MOSFET switch.
- **⚠️ Prohibition of High-Frequency PWM:**
  - **Never apply high-frequency PWM (e.g. 490 Hz – 20 kHz) to control mist output.**
  - The internal driver is an analog self-oscillating LC inverter (using an RF power BJT/MOSFET tuned to the ceramic disc's 1.7 MHz resonance).
  - It requires **50–200 ms** under continuous DC voltage to stabilize its oscillation tank and build the surface capillary acoustic wave.
  - Chopping the power rail at PWM frequencies causes excessive switching losses, extreme transistor heating, and prevents cavitation.
- **Recommended Control Mode:** **Bang-Bang / Time-Proportional Switching.**
  - Regulate ambient humidity by turning the 24 V supply ON and OFF in macro-intervals:
  - Minimum ON time: **≥ 10 seconds**
  - Minimum OFF time: **≥ 15 seconds**
  - Use an anti-short-cycle timer in firmware to prevent rapid chattering around the humidity threshold.

---

## 3. Hydrological Dynamics & Vessel Geometry

### 3.1 Resolving the "20–75 mm" Specification Confusion
The generic vendor specification typically states *"Water level: 20–75 mm"*.
In real installation, **20–75 mm refers to the height of water above the ceramic disc face**, **not** from the bottom of the container.

Because the ceramic disc sits inside a recessed central well approximately **22 mm above the vessel base**, all critical measurements from the vessel floor are:

```
 Total Depth
 from Base
   ▲
   │
55 ┼ ─ ─ ─ ─ ─ ─ ─ ─ ─ ─ ─ ─ ─ ─ ─ ─ ─ ─ ─ ─  Choking / Splatter Zone (>50 mm)
50 ┼ ─ ─ ─ ─ ─ ─ ─ ─ ─ ─ ─ ─ ─ ─ ─ ─ ─ ─ ─ ─  Heavy hydrostatic head dampens cavitation; throws drops
   │
47 ┼ ───────────────────────────────────────  Optimal Upper Limit (Cap ON)
   │ ░░░░░░░░░░░░░░░░░░░░░░░░░░░░░░░░░░░░░░░  SWEET SPOT (42–47 mm)
44 ┼ ───────────────────────────────────────  Optimal Lower Limit (Cap OFF)
   │
41 ┼ ─ ─ ─ ─ ─ ─ ─ ─ ─ ─ ─ ─ ─ ─ ─ ─ ─ ─ ─ ─  Safety Probe Threshold (~41 mm)
   │                                          Unit shuts down below this line
   │            ┌─────────┐
   │            │ ░░░░░░░ │  <-- Splash guard / collar (top at 45 mm)
   │            │         │
22 ┼ ─ ─ ─ ─ ─ ─┤ [PIEZO] ├─ ─ ─ ─ ─ ─ ─ ─ ─  Piezo disc surface (~22 mm from floor)
   │      ┌─────┘         └─────┐
   │      │   Potted Chassis    │
 0 ┴ ─────┴─────────────────────┴───────────  Vessel Floor (0 mm)
```

1. **Safety Cut-Off Line (`41 mm` total depth):**
   - The metal pin protruding upward beside the central chimney is an electrical conductivity sensor.
   - It requires liquid contact between the probe tip and the grounded casing to bias the oscillator on.
   - When liquid drops below **41 mm**, the circuit opens and oscillation halts instantly.
   - *(Note: Some vendor descriptions claim this module lacks a water sensor. That is factually incorrect; physical inspection confirms the conductive sensing probe is present).*
2. **Optimal Mist Band (`42 mm – 47 mm` total depth):**
   - Highest mist output occurs when the water column standing directly above the ceramic disc is **20 mm to 25 mm** deep.
   - At this level, ultrasonic energy efficiently focuses at the liquid-air interface to generate high-density capillary wave micro-droplets without bubbling violently.
3. **Choking Threshold (`> 50 mm` total depth):**
   - As water depth exceeds 50 mm from the base (> 28 mm above the disc), hydrostatic head pressure absorbs the acoustic shock waves.
   - Mist production drops sharply, and the module throws coarse water droplets instead of a dry fog.
4. **Effective Working Bandwidth:**
   - The functional operating window is only **~6 mm to 10 mm** wide (between probe cut-off at 41 mm and acoustic damping at ~50 mm).
   - In an open, unregulated chamber, evaporation will consume this band in a short time. A **constant-level replenishment system** (such as an external Mariotte siphon bottle or float valve) is strongly recommended for automated systems.

---

## 4. Mechanical & Dimensional Details

```
              ┌─── Ø 20 mm Disc ───┐
              ▼                    ▼
          ┌───────┐            ┌───────┐
          │       │  [Probe]   │       │
          │       │    │       │       │
          │       └──┐ │ ┌─────┘       │ ◄── Splash collar / chimney
   45 mm  │          │ │ │             │
          │   ┌──────┴─┴─┴──────┐      │
          ├───┘                 └───┬──┤ ◄── Cable entry with strain relief
          │                         │  │
          │   Solid Epoxy Potted    │  │
          │    Driver Circuitry     │  │
          └─────────────────────────┴──┘
          ◄────────── Ø 45 mm ─────────►
```

- **Outer Diameter:** 45.0 mm.
- **Overall Height:** 45.0 mm (from base feet to the top edge of the splash collar).
- **Base Cylinder Height:** ~25.0 mm.
- **Collar / Chimney Height:** ~20.0 mm above main body shoulder.
- **Disc Recess:** ~23.0 mm below the top edge of the collar.
- **Cable:**
  - Standard length: **1.40 m** (1400 ± 20 mm).
  - Marking: `AWM 2464 24AWG 80°C 300V VW-1`.
  - Outer diameter: **3.8 mm**.
  - Pass-Through Seal: Includes a sliding conical rubber bung (OD tapering from ~14 mm to ~11 mm, with an 8 mm center collar) suitable for sealing against a chamfered hole in a chamber wall.
- **Repairability / Serviceability:**
  - **Non-serviceable assembly.**
  - The transducer cavity and bottom electronics are factory-potted in rigid black epoxy resin to achieve IP68 submersion protection.
  - The ceramic disc is bonded and sealed with factory compound; it does not utilize an accessible screw-retaining ring. If the disc fractures, the entire module must be replaced as a consumable unit.

---

## 5. Water Quality & Operational Maintenance

### 5.1 Water Chemistry
- **Recommended Water:** **Demineralized, Deionized, or Reverse Osmosis (RO) water.**
- **Impact of Tap / Hard Water:**
  - Tap water dissolved minerals (calcium, magnesium) precipitate on the vibrating face of the ceramic disc due to intense local cavitation heat.
  - Mineral scale creates acoustic impedance mismatches, cuts mist output by >50 % within weeks, and creates hot-spots that crack the ceramic element.
  - Mineral aerosols from hard water also leave white mineral dust in the terrarium / enclosure.

### 5.2 Descaling & Cleaning Protocol
1. Disconnect 24 V power before removing the module from water.
2. If mineral deposits or biological films appear:
   - Submerge the head in a **50:50 solution of warm water and white vinegar** (or 5% citric acid solution) for **20–30 minutes**.
   - Gently wipe the surface of the ceramic disc and the metal probe using a **soft cotton swab**.
   - **Never** use steel wire, razor blades, metallic screwdrivers, or abrasive pads, as scratching the gold/silver electrode film on the disc will permanently ruin it.
3. Rinse thoroughly with clean RO water before placing back into service.

### 5.3 Duty Cycle Guidelines
- **Continuous Operation Limit:** Do not run continuously for more than **8 to 10 hours** without resting. In intermittent terrarium climate control (e.g. 1–3 minutes per humidity cycle), component lifespan is maximized.
- **Transducer Lifespan:** Rated for **3,000 to 5,000 hours** of cumulative oscillation under clean water conditions.

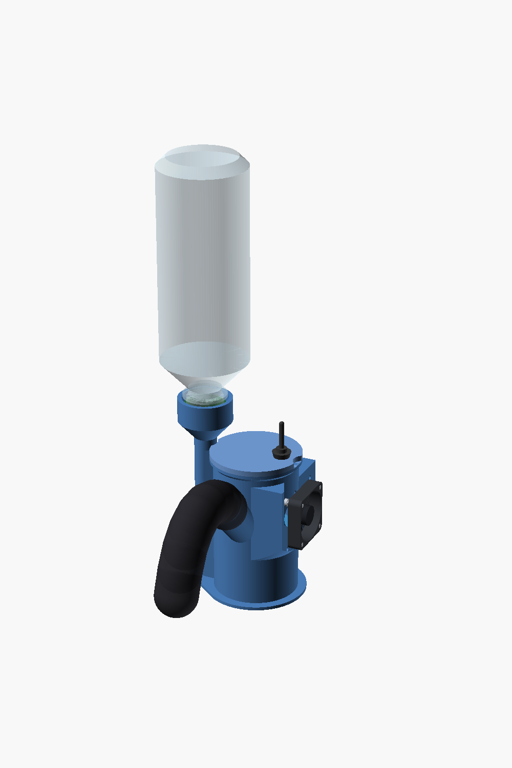
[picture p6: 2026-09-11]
cad/render/assembly.png

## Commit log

2026-09-02 Document the automated snail terrarium project
    Initial documentation for a self-regulating 46x28x37 cm snail habitat
    built on an ESP8266 running Climate Panel Pro firmware.
    - README.md: project overview, habitat spec, climate targets, system
    architecture, component list, roadmap and welfare notes
    - HARDWARE.md: bill of materials, power budget and topology, pin map,
    wiring diagrams, flashing procedure, first-power-on checklist
    - AUTOMATION.md: per-output control config with reasoning, the
    empty-tank commissioning week, history-graph tuning table and
    failure modes
    Two open hardware questions are flagged rather than assumed: three
    switched loads share only two MOSFET modules, and the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
2026-09-02 Add parametric CAD for the fog chamber and lid
    Set up an OpenSCAD project driven by a single shared parameter file, so
    every dimension traces back to a measured or datasheet value and the STLs
    regenerate when one changes.
    - cad/params.scad: all dimensions, tagged CONFIRMED / ASSUMED / MEASURE
    - cad/chamber.scad: fog chamber, 96x96x183 mm, prints upright without support
    - cad/lid.scad: removable lid with fill port, vent ring and cable notch
    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
    [chamber.scad, chamber.stl, lid.scad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]
2026-09-02 Fix printability and fit defects found in pre-print verification
    Add cad/verify.py and work through what it found. None of these were
    visible in a render, and all of them would have shipped in a 288 g PETG
    part.
    - teardrop() extruded its point downward, so every horizontal hole kept a
    90 degree overhang at the crown - the exact thing the teardrop exists to
    avoid
    - water levels were measured from the chamber floor rather than the
    module's top face, putting the fill line 76.5 mm above it against a
    75 mm ceiling; levels now carry the recess depth and sit inside the band
    with margin at both ends
    - the lid's finger recess was an 8 mm sphere cut into an 8 mm lid, leaving
    a knife edge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
    [chamber.scad, chamber.stl, check.scad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]
2026-09-02 Switch to a bottle-fed Mariotte reservoir to cut print cost
    The reservoir-less chamber quoted at 4 M toman. Sizing a vessel by
    footprint x tolerance band made it far larger than the job needs.
    An inverted-bottle siphon holds the level constant, which lets the level
    sit at the bottom of the module's 20-75 mm band instead of filling to the
    top, and moves capacity out of the printed part entirely:
    plain chamber 293 cm3 / 373 g / 22 days
    bottle + siphon 134 cm3 / 170 g / 25 days
    - cylindrical 74 mm bore chamber, sized only by the 45 mm module
    - lid carries an integral standpipe whose bottom opening sets the level,
    offset 16 mm so it does not sit over the atomising disc
    - TPU washe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
    [chamber.scad, chamber.stl, dump_params.scad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]
2026-09-02 Slim the chamber after a real print quote
    A quote of 2.44 M toman for the 83.6 g chamber works out at ~29,000 per
    gram, far above material cost - so the price is machine time, and time on
    FDM tracks layer count. The chamber was 126.5 mm tall at 100 micron:
    1,265 layers.
    Reduce both mass and height:
    - walls 2.5 -> 2.0 mm (5 perimeters at a 0.4 mm nozzle, still watertight)
    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
    [chamber.stl, gasket.stl, lid.stl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]
2026-09-02 Size walls to an exact perimeter count for watertightness
    A print service exposes infill but not perimeter count, and for a vessel
    the perimeters are what seal it. At 2 perimeters on a 0.4 mm nozzle a
    2.0 mm wall is 0.8 mm of shell around 1.2 mm of 20% infill, which weeps
    no matter what the infill is set to.
    Make the wall exactly 4 extrusions instead, so it is 100% shell:
    - ch_wall 2.0 -> 1.6 mm, sp_wall likewise
    - add a 3 mm rim flange at the top, since a 1.6 mm wall leaves too narrow
    a ledge for the lid to seat on; it also stiffens the rim of a thin tube
    - lid plate widened to match the flange
    chamber 65.9 -> 57.7 cm3
    total 107 -> 99 cm3, 135 -> 126 g
    Thinner here is both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
    [chamber.scad, chamber.stl, dump_params.scad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]
2026-09-02 Add vessel_lid: use a cut PET bottle as the chamber
    At ~29,000 toman per gram the price is machine time, so printing a plain
    water container is the worst use of the budget. A PET bottle cut into a
    cup holds the water for nothing, is more watertight than any FDM part,
    and is transparent so the level is visible.
    printed cylinder + lid 99 cm3 / 126 g / 120 mm tall
    cut bottle + vessel_lid 40 cm3 / 51 g / 66 mm tall
    The lid's skirt is a shallow cone so it self-centres over a 5 mm spread
    of bottle diameters - brands vary and there is no reason to force an
    exact match. It needs no seal: water sits at 66.5 mm and the joint is at
    the 120 mm cut, so it is never wet.
    Fixes a defect the mesh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
    [chamber.stl, dump_params.scad, gasket.stl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]
2026-09-02 Drop the reservoir: the level can drift down the band
    Re-derived the design after the vessel became a free cut bottle, and the
    Mariotte reservoir does not survive the review.
    Its purpose was holding the level constant so an expensive printed vessel
    could be small - capacity cost footprint x band in PETG. Once the vessel
    was free, capacity was free, and the reason for the reservoir went with
    it. It was carried forward on momentum.
    The module's 20-75 mm band is 55 mm wide, so the level can simply drift:
    a 1.5 L bottle gives ~17 days, a 2 L ~23. That is endurance obtainable by
    cutting a bigger empty bottle, against the cost of a standpipe, a neck
    seal, a second bottle to keep upright, a sipho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
    [chamber.stl, dump_params.scad, gasket.stl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]
2026-09-03 Replace guessed module dimensions with measured ones
    Running the actual unit in a bowl of water gave the numbers that no
    datasheet or photograph had:
    module height 45 mm (spec was right; my photo estimate was not)
    starts working 41 mm water depth from the vessel floor
    works 42-50 mm
    labours, splashes >50 mm
    The vendor's "effective water level 20-75 mm" is measured from the
    ceramic disc recessed in the well, not from the base, which is why it
    never reconciled with anything.
    Three consequences:
    - The usable band is 9 mm, not 55. An unregulated vessel is a ~3 day
    refill, so the bottle feed is required. This reverses the earlier
    decision to drop t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
    [cap_chamber.scad, chamber.scad, chamber.stl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]
2026-09-03 Draw the bottle-fed mist body
    Follows the Orchidee arrangement, sized to the measured module. A bottle
    screws into the top of a conduit that runs up the OUTSIDE of the chamber
    and enters through a port at the water line; that port's height is what
    sets the level.
    - mister.scad PART="body"/"lid"/"fan30"
    - fan mount left generic: the body carries one pad drilled for a 40 mm
    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
    [dump_params.scad, gasket.stl, mister.scad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]
2026-09-03 Cut the body's mass where the quotes showed it was going
    Four quotes at 200 micron give a flat rate of roughly 15,000 toman per
    gram, independent of part height:
    4.5 g / 3 mm 17,500/g
    13 g / 9 mm 14,700/g
    34 g / 15 mm 13,600/g
    89 g / 104 mm 15,500/g
    So within one layer height the cost tracks MASS, not layer count. That
    corrects the earlier conclusion that height was the lever - height only
    mattered because it came with mass. Layer height still halves the rate
    (the 100 micron body was 29,200/g).
    The feed conduit was 37% of the body at 33 g. Its 4 mm wall existed only
    to widen a geometry window, and its 20 mm bore was carrying about 20 ml
    a day:
    - feed bore 20 -> 12 mm,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
    [dump_params.scad, gasket.stl, mister.scad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]
2026-09-03 Make the bottle screw in, using a captured bottle cap
    The socket was a smooth push-in bore sealed by a TPU washer under the
    bottle's support ring. For an inverted bottle full of water that is
    weak: nothing holds it down and the seal relies on the bottle's weight.
    It now takes a real PET bottle cap, press-fitted into a pocket in the
    boss and drilled through. The thread is then injection-moulded and the
    seal is the cap's own liner against the bottle rim, which is what that
    liner is designed to do. Printing a PCO-1881 thread instead means a
    3-start profile at FDM tolerances on a joint that must not leak.
    The TPU gasket is no longer needed and is dropped from the build.
    Two faults the checks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
    [dump_params.scad, mister.scad, mister_body.stl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]
2026-09-03 Position the feed port by its top edge, add a module spacer
    The chimney cap turns out to be removable, and the water test was run
    without it - so the 41-50 mm range describes the cap-off configuration,
    not the cap-on one that was asked for. Rather than guess or wait, the
    part now covers both.
    Two faults found getting there:
    - The port was positioned by its CENTRE. The siphon stabilises where air
    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
    [dump_params.scad, mister.scad, mister_body.stl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]
2026-09-03 Remove STLs for the dropped plug and gasket
    [gasket.stl, mister_plug.stl]
2026-09-09 Rebuild the mist chamber against the measured module datasheet
    Auditing the previous body with booleans instead of reading it found
    eight defects, three of which made the part impossible to assemble:
    - the feed bore was blocked by a 3 mm slug of PETG below the cap
    pocket (337.9 mm3), so the bottle fed nothing
    - the lid collided with the bottle socket by 375.6 mm3 and could
    not be seated
    - two of the four fan screw holes opened into the chamber below
    the water line, and the fan bore itself dipped 0.4 mm under it
    - the nozzle spigot was bonded to the barrel over 0.2 mm3
    - the module "recess" was cut into the underside of the floor,
    leaving a 0.9 mm membrane holding t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
    [cap_chamber.scad, chamber.scad, check.scad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]
2026-09-09 Add the assembly model, an interactive viewer, and the docs for both
    The printed parts were verified but never shown together. cad/assembly.scad
    adds that: it includes params.scad and uses mister.scad, so the printed parts
    in it are the printed parts, and the bought ones are built from their own
    documentation - the module from MIST-MAKER.md section 4, the reservoir as a
    standard PET neck finish. Change a dimension and the picture changes with it.
    EXPLODE / SECTION / BOTTLE switch what it draws; four stills are in
    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
    [assembly.scad, export_parts.scad, mister_body.stl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]
2026-09-09 Lengthen the fog nozzle so a hose can actually go on it
    Spotted in the viewer, not by a check. The nozzle looked far too short to push
    a hose onto, and measuring it was worse than looking: sliding a modelled hose
    down the nozzle axis until it fouled the barrel gave under 4 mm of usable seat
    on an 18 mm spigot.
    That is geometry peculiar to an inclined protrusion. A spigot leaving a round
    barrel at 45 degrees is buried unevenly - its upper side runs much deeper into
    the wall than its lower side - and the hose stops against the short side. It is
    also the hose's outer BACK CORNER that hits first, not its bore, so the length
    lost is set by the hose's outer radius:
    (25/2 + 3) x tan(45) = 15.5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
    [checks.scad, mister_body.stl, mister_lid.stl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]
2026-09-10 Keep the assembly viewer as a project document, and host it
    The built page was gitignored as generated output. That was the wrong call:
    it is a document of the project in its own right. It opens on any machine,
    years from now, with no toolchain, no network, no OpenSCAD and no Python -
    everything it needs, geometry and three.js included, is inside the one file.
    The cost is that each rebuild writes a fresh ~816 KB blob into history, which
    is a fair price for a page that still works when nothing else does.
    cad/viewer/index.html is therefore tracked, and viewer.py gains --deploy:
    build, then push to Vercel as a production deployment. Building first is the
    point - deploying a stale index.html is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
2026-09-10 Tidy the repo: honest folder names, binary meshes, a navigable journal
    Folders now say what they hold. cad/stl/ was a misnomer - it carried three
    meshes, two orphaned PNGs, an SVG and a views/ subfolder. It is now meshes
    only, and cad/render/ holds the pictures.
    cad/stl/ mister_body|lid|spacer.stl written by verify.py
    cad/render/ four views + section.svg written by viewer.py --stills
    Meshes are exported as binary STL rather than OpenSCAD's default ASCII. Same
    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
    [mister_body.stl, mister_lid.stl, mister_spacer.stl]
2026-09-11 Deploy the viewer from git, now that Vercel builds cad/viewer/
    The site was returning 404 on every path but one. The Vercel project had
    its Root Directory at the repository root, so a push deployed the whole
    repo - which has no index.html at "/" - and the viewer was sitting at
    /cad/viewer/index.html, reachable but not where the link pointed. The
    deployment reported healthy throughout.
    Root Directory is now cad/viewer, which also means a git push publishes
    the page. That breaks the old `viewer.py --deploy`: Vercel applies the
    root directory on top of whatever you upload, so deploying from inside
    cad/viewer/ now fails with `Root Directory "cad/viewer" does not exist`.
    --deploy therefore push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
2026-09-11 Cut the bottle socket for the cap standards, not for one measured cap
    cap_od and cap_h were the last two numbers in params.scad marked
    MEASURE, and they cut real geometry: the pocket, the ribs, and through
    pocket_depth = cap_h + 1 the height of the socket's top face. Getting
    them wrong meant reprinting a 119 g part. Looking up what caps actually
    are showed the guard was aimed at the wrong number:
    28 mm PCO-1881 soda, 2009- cap Ø30.4 ±0.3 11-13 mm tall
    28 mm PCO-1810 soda, older cap Ø31.0 ±0.4 14-17 mm tall
    29/25, 30/25 still water cap Ø29.5-31 8-12 mm tall
    Diameter varies by under 2 mm. Height varies by 9 mm, and height was
    the one wired into the geometry. IS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
    [assembly.scad, checks.scad, export_parts.scad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]
2026-09-11 Derive the fan pad height so both bolt patterns get a flat seat
    The 45 deg chamfer under the fan pad is deliberate - D15 put it there
    because the pad's flat underside would otherwise be the one horizontal
    ceiling on the part. What nobody followed through was what it does to
    the face ABOVE it.
    The seating face only exists where the chamfer cone has grown past the
    corner it has to reach, and that distance goes with y:
    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
    [mister_body.stl, params.scad]
2026-09-11 Drill the fan pad for 30, 40 and 50 mm fans
    Which fan actually does the job through a Ø26 bore is a question you
    answer by trying them, and the pad was committing you to one of two
    before you could. It now carries three bolt patterns - 24, 32 and
    40 mm pitch - and since D25 made fan_pad derive from the widest
    pattern rather than a picked number, adding one costs only the
    arithmetic:
    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
    [mister.scad, mister_body.stl, params.scad]
2026-09-16 Export the lid lying the way it prints
    The lid was modelled, and exported, the way it sits on the chamber:
    spigot down, plate on top. verify.py flipped it in memory before the
    overhang check, so the gate passed - but the STL itself was upside
    down for printing. The print service slices a file as uploaded and has
    no rotate control, so that file would have printed with the whole
    plate over air:
    as exported 3062 mm2 overhanging past 45°
    plate on bed 1 mm2 (the countersink nicking the spigot)
    mister.scad now turns the lid over at export. It is a rotation about
    x, not a z-mirror: a mirror would put the cable hole on the wrong side
    of the feed relief and still pass every check. ass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
    [mister.scad, mister_lid.stl]
2026-09-16 Bring the docs in line with the design, and record the first order
    The settled water level was quoted as 43.6-46.0 mm with a 2.4 mm
    bubble head in the README, VIEWER.md, D21, params.scad and the viewer's
    gauge. The gate computes it: 4*sigma/d on a Ø12 port is 2.47 mm, and
    verify.py prints 2.5 and 43.5. Those are the figures a ruler gets held
    against at commissioning, so they now match everywhere. The same slip
    put "centring the port" at 42.5 mm; it is 42.0, 1.0 mm off the probe.
    Other things that were wrong:
    README ../.venv from the repo root, which does not resolve;
    a status line and roadmap that predate the chamber
    D19, comments the countersink "narrows as it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
    [mister.scad, params.scad]
